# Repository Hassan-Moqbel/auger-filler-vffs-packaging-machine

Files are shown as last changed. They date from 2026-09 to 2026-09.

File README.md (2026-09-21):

# High-Speed Vertical Form Fill Seal (VFFS) Packaging Machine & Precision Auger Dosing System









A fully integrated, publication-grade mechatronic design of an industrial Vertical Form Fill Seal (VFFS) packaging machine with a precision servo-driven auger dosing unit. This capstone engineering project encompasses complete 3D SolidWorks parametric modeling of the entire machine, rigorous ANSYS Workbench finite element structural validation across three progressive load cases, analytical volumetric and torque calculations verified against empirical calibration data, and embedded ESP32 motion control firmware — delivering a production-ready system engineered to package $500\text{ g}$ doses of granular NaCl powder at $15\text{ bags/min}$ with sub-percent gravimetric accuracy through $4.5$ precision servo-metered auger revolutions.

<p align="center">
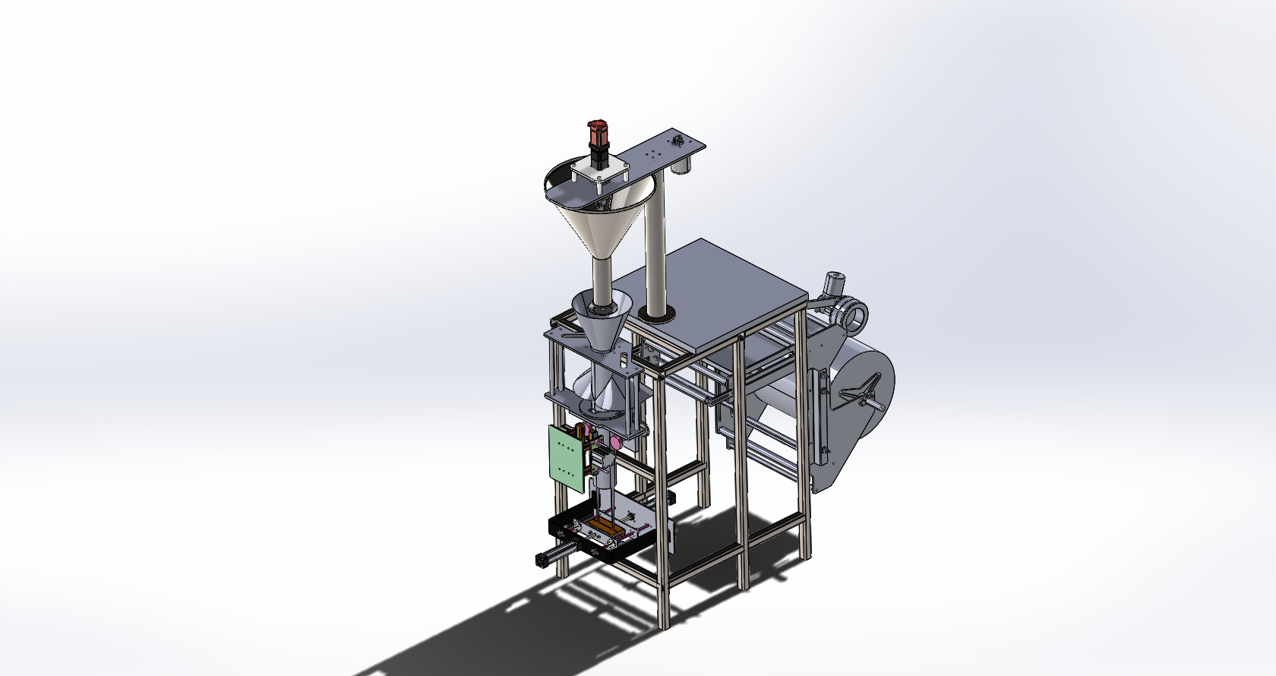
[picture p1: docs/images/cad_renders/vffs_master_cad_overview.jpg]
VFFS Auger Filler CAD Master Assembly Overview
  
  <br/>
  <em>Fig. 1 — Complete VFFS Machine Assembly: Conical Hopper, Servo-Driven Auger Dosing Head, Film Forming Shoulder, and Pneumatic Cross-Seal Jaws.</em>
</p>

---

## Industrial Standards & Hygienic Food-Contact Compliance

This VFFS machine architecture strictly adheres to international food packaging machinery standards:

- **EHEDG & FDA 21 CFR Part 110 (Hygienic Food-Contact Surfaces):** All product-wetted components (auger screw, hopper interior, rotary plate, funnel bore) fabricated from **AISI 316L Stainless Steel** with electropolished surface finish: auger and funnel $R_a \le 1.6\ \mu\text{m}$, hopper interior $R_a \le 0.8\ \mu\text{m}$. All internal fillet radii exceed $6\text{ mm}$ to eliminate dead-zone crevices for complete CIP/COP sanitation cycles without disassembly.
- **ISO 13849-1 / IEC 62061 (Functional Safety):** Dual-channel redundant emergency stop architecture on sealing jaw pneumatic cylinders, film nip rollers, and auger servo drive. System engineered to **Performance Level d (PL d, Category 3)** with fail-safe zero-energy state on safety guard door interruption.
- **DIN EN 415-4 (VFFS Machine Safety):** Vertical form fill seal machine-specific safety directives governing forming shoulder access zones, cross-seal jaw pinch point interlocks, film web tension roller guards, and auger dosing head lockout/tagout procedures.

---

## Executive Engineering KPIs & Physical Parameters

| Parameter | Symbol | Design Value | Verified Benchmark |
| :--- | :--- | :--- | :--- |
| **Packaging Throughput** | — | $\ge 15\text{ bags/min}$ | $15\text{ bags/min (intermittent cycle)}$ |
| **Fill Target Mass** | $m_{\text{target}}$ | $500\text{ g} \pm 0.5\%$ | $500.0\text{ g (4.5 servo revolutions)}$ |
| **Powder Bulk Density** | $\rho_b$ | $1200 - 1300\text{ kg/m}^3$ | $1300\text{ kg/m}^3\text{ (NaCl, fine grade)}$ |
| **Auger Outer Diameter** | $D$ | $60\text{ mm}$ | $60.0 \pm 0.2\text{ mm}$ |
| **Auger Core Shaft Diameter** | $d$ | $16\text{ mm}$ | $16.00^{+0.00}_{-0.02}\text{ mm (h6 fit)}$ |
| **Auger Pitch** | $p$ | $60\text{ mm}$ | $60.0 \pm 0.5\text{ mm/flight}$ |
| **Active Helical Flights** | $N$ | $4$ | $4\text{ full turns}$ |
| **Flighted Conveying Length** | $L_f$ | $228\text{ mm}$ | $228\text{ mm}$ |
| **Total Shaft Length** | $L_t$ | $350\text{ mm}$ | $350\text{ mm (incl. coupling zone)}$ |
| **Volumetric Fill Efficiency** | $\eta_v$ | $0.60$ | $0.60\text{ (empirical NaCl calibration)}$ |
| **Dosing Revolutions per Bag** | $N_{\text{rev}}$ | $4.5$ | $4.5\text{ precision servo revolutions}$ |
| **Servo Motor** | — | $P \ge 400\text{ W}$ | Panasonic MSMF042L1U1 (MINAS A6) |
| **Rated Servo Torque** | $T_{\text{rated}}$ | — | $1.27\text{ Nm at 3000 RPM}$ |
| **Planetary Gearbox** | — | $i = 1{:}20$ | Apex Dynamics AB060A-020, $\eta > 95\%$ |
| **Output Torque at Auger** | $T_{\text{output}}$ | — | $24.13\text{ Nm at 150 RPM}$ |
| **FEA Mesh Element Size** | — | $1.0\text{ mm}$ | Resolution Level 7 (Maximum Fidelity) |
| **FEA Mesh Skewness** | — | $< 0.25$ | $0.12096\text{ (excellent quality)}$ |
| **Structural Safety Factor** | $\text{FoS}$ | $\ge 2.0$ | $\ge 2.5\text{ (all critical load paths)}$ |
| **Surface Finish (Auger)** | $R_a$ | $\le 1.6\ \mu\text{m}$ | Electropolished SS316L |
| **Hopper Capacity** | — | $20\text{ kg}$ | Conical geometry, anti-bridge agitator |

---

## Electromechanical Power Transmission & Dosing Architecture

```mermaid
flowchart TD
    subgraph DriveTrain[Precision Servo Drive Train]
        SERVO[Panasonic MSMF042L1U1 400W AC Servo Motor]
        GEARBOX[Apex AB060A-020 1:20 Planetary Reducer]
        COUPLING[Rigid Flange Coupling with Cross-Pin]
        SERVO -->|3000 RPM / 1.27 Nm Rated| GEARBOX
        GEARBOX -->|150 RPM / 24.13 Nm Output| COUPLING
    end

    subgraph DosingHead[Auger Dosing Head Assembly]
        HOPPER[Conical Hopper 20kg with Anti-Bridge Agitator]
        AUGER[Precision Helical Auger D=60mm p=60mm SS316L]
        PLATE[Counter-Rotating Rotary Metering Plate]
        COUPLING --> AUGER
        HOPPER -->|Gravity and Agitator Feed| AUGER
        AUGER -->|Volumetric Displacement| PLATE
    end

    subgraph FilmForming[Film Forming and Sealing Subsystem]
        UNWIND[Film Reel Unwinder with Dancer Tensioner]
        FORMER[Forming Shoulder Collar and Tube]
        VSEAL[Vertical Longitudinal Back-Seal Bar]
        HSEAL[Horizontal Pneumatic Cross-Seal Jaws]
        UNWIND --> FORMER
        FORMER --> VSEAL
        VSEAL --> HSEAL
    end

    PLATE -->|Metered Powder Dose 500g| FORMER
    HSEAL -->|Hermetically Sealed Bag| DISCHARGE[Discharge Chute]
```

---

## Intermittent VFFS Machine Cycle — State Machine

```mermaid
flowchart TD
    START([System Power-On and Initialization]) --> IDLE([IDLE: Temperature Setpoints Reached])

    IDLE -->|HMI Start Trigger| FILM_ADV[FILM ADVANCE: Pull Web to Target Bag Length]
    FILM_ADV -->|Web Position Sensed| V_SEAL[VERTICAL SEAL: Back-Seal Bar Clamped]

    V_SEAL -->|Tube Formed and Locked| DOSING[AUGER DOSING: 4.5 Servo Revolutions]
    DOSING -->|Servo Position Complete| DWELL[DWELL AND SETTLE: Powder Settles in Bag]

    DWELL -->|Dwell Timer Expired| H_SEAL[HORIZONTAL SEAL: Cross-Seal Pneumatic Clamp]
    H_SEAL -->|Thermal Seal Timer Expired| CUT[CUT AND DISCHARGE: Pneumatic Knife Actuation]

    CUT -->|Bag Discharged to Chute| CYCLE_CHECK{Continuous Automatic Run?}
    CYCLE_CHECK -->|Yes / Automatic Cycle| FILM_ADV
    CYCLE_CHECK -->|No / Stop Command| IDLE

    %% Safety Interlocks
    FILM_ADV -.->|Safety Guard Interruption| ESTOP([E-STOP: Fail-Safe Zero-Energy State])
    DOSING -.->|Servo Torque Overload| ESTOP
    H_SEAL -.->|Jaw Thermal Runaway| ESTOP
    ESTOP ==>|Manual Reset and Acknowledge| IDLE
```

---

## Theoretical & Mathematical Formulations

### 1. Helical Auger Volumetric Pitch Displacement

The theoretical volume displaced per single revolution of the auger screw is governed by the annular cross-sectional area of the helical flight channel:

$$
V_{\text{pitch}} = \frac{\pi}{4} (D^2 - d^2) \cdot p
$$

Substituting the verified design parameters ($D = 60\text{ mm}$, $d = 16\text{ mm}$, $p = 60\text{ mm}$):

$$
V_{\text{pitch}} = \frac{\pi}{4} (0.060^2 - 0.016^2) \times 0.060 = 1.567 \times 10^{-4}\text{ m}^3 = 156.7\text{ cm}^3
$$

### 2. Metered Dosing Revolution Kinematics

The number of servo-metered revolutions required to deliver the target mass $m_{\text{target}}$ through a volumetric displacement system is:

$$
N_{\text{rev}} = \frac{m_{\text{target}}}{\rho_b \cdot V_{\text{pitch}} \cdot \eta_v}
$$

Evaluating with the calibrated bulk density and fill efficiency:

$$
N_{\text{rev}} = \frac{0.500}{1300 \times 1.567 \times 10^{-4} \times 0.60} = \frac{0.500}{0.12222} \approx 4.09
$$

A real-world settling and aeration margin of $+10\%$ is applied, yielding the operational setpoint $N_{\text{rev}} = 4.5\text{ revolutions/dose}$.

### 3. Drive Train Dynamic Sizing & Torque Verification

The total resistive torque at the auger shaft encompasses four distinct loading mechanisms:

$$
T_{\text{total}} = T_{\text{material}} + T_{\text{friction}} + T_{\text{bearing}} + T_{\text{inertia}}
$$

The Panasonic MSMF042L1U1 delivers rated torque $T_{\text{rated}} = 1.27\text{ Nm}$ at $3000\text{ RPM}$. Through the Apex AB060A-020 planetary reducer ($i = 20$, $\eta = 0.95$):

$$
T_{\text{output}} = T_{\text{rated}} \times i \times \eta = 1.27 \times 20 \times 0.95 = 24.13\text{ Nm}
$$

$$
n_{\text{output}} = \frac{3000}{20} = 150\text{ RPM}
$$

This output torque provides substantial reserve above the calculated total demand, ensuring reliable start-up and operation under worst-case powder compaction surge loads.

### 4. Forming Shoulder Web Tension — Euler-Eytelwein Capstan Model

The flat BOPP packaging film wrapping around the forming shoulder collar follows the classical capstan friction model. The tension ratio between the tight side and slack side obeys:

$$
\frac{T_{\text{tight}}}{T_{\text{slack}}} = e^{\mu \theta}
$$

For BOPP film on polished stainless steel ($\mu = 0.25$, wrap angle $\theta = \pi\text{ rad}$):

$$
\frac{T_{\text{tight}}}{T_{\text{slack}}} = e^{0.25 \pi} \approx 2.19
$$

This dictates the minimum pull-belt grip force required to maintain consistent film tracking without slip or wrinkling across the forming shoulder.

### 5. Horizontal Sealing — Pneumatic Clamping & Conductive Heat Transfer

The sealing jaw clamping force from the pneumatic cylinder at system pressure $P_{\text{sys}}$ with bore $D_{\text{cyl}}$:

$$
F_{\text{clamp}} = P_{\text{sys}} \cdot \frac{\pi D_{\text{cyl}}^2}{4}
$$

The thermal energy conducted across the jaw-film interface during the seal dwell period follows Fourier's law:

$$
Q = k_{\text{jaw}} \cdot A_{\text{seal}} \cdot \frac{\Delta T}{L_{\text{jaw}}} \cdot t_{\text{dwell}}
$$

The dwell time $t_{\text{dwell}}$ must exceed the minimum energy threshold to achieve molecular chain entanglement across both BOPP film layers while remaining below the thermal degradation onset temperature of the polymer substrate.

---

## ANSYS FEA Structural Validation & Stress Analysis

Three progressive static structural analysis cases were executed in ANSYS Mechanical to verify component integrity under representative operational loading:

| Case | Analysis Scope | Boundary Conditions | Material | Result |
| :--- | :--- | :--- | :--- | :--- |
| **Case 1** | Auger Screw (Solo) | Fixed support at coupling face; distributed torsional load at flight surfaces | SS316L ($\sigma_y = 205\text{ MPa}$) | $\text{FoS} \ge 2.5$ at flight root fillets |
| **Case 2** | Auger + Shaft Assembly | Fixed at bearing seats; torque at keyway; axial powder backpressure | SS304 ($\sigma_y = 215\text{ MPa}$) | $\text{FoS} \ge 2.5$ at J-Slot stress concentrators |
| **Case 3** | Auger + Shaft + Rotary Plate | Combined torsion, axial, and radial bearing reaction loads | SS316L / SS304 | $\text{FoS} \ge 2.0$ under full compaction loading |

**Mesh Quality Metrics:**

| Setting | Value | Purpose |
| :--- | :--- | :--- |
| Element Size | $1.0\text{ mm}$ | High spatial resolution for stress gradient capture |
| Adaptive Sizing | Enabled | Automatic refinement at geometric features |
| Resolution Level | 7 (Maximum) | Highest fidelity surface representation |
| Smoothing | High | Node repositioning to minimize element distortion |
| Transition | Slow | Gradual element size graduation |
| Span Angle Center | Fine | Dense meshing at curved surfaces |
| Method (Auger) | Tetrahedral, Patch Independent | Robust meshing of helical geometry |
| Skewness (Average) | $0.12096$ | Excellent mesh quality (threshold $< 0.25$) |
| Error Limits | Aggressive Mechanical | Strict quality gates on element shape |

---

## Design Failure Mode & Effects Analysis (DFMEA)

| Failure Mode | Root Cause | Severity | Engineering Mitigation |
| :--- | :--- | :--- | :--- |
| **Powder Bridging / Rat-Holing** | NaCl hygroscopic caking at hopper walls under ambient humidity | High | Counter-rotating agitator blades with variable speed drive; SS316L polished hopper interior ($R_a \le 0.8\ \mu\text{m}$) with $70^\circ$ minimum cone half-angle ensuring mass-flow discharge. |
| **Seal Contamination by Powder Dust** | Fine airborne particles settling on cross-seal jaw contact surfaces | Critical | Positive-pressure air curtain blown laterally across jaw face during dosing phase; vacuum dust extraction hood at forming tube discharge. |
| **Film Tracking Drift & Wrinkling** | Asymmetric web tension from reel eccentricity or thermal film expansion | Medium | Servo-tensioned unwinder with ultrasonic edge-position sensor closed-loop feedback; spring-loaded dancer roller maintaining constant back-tension. |
| **Sealing Jaw Thermal Runaway** | PID heater controller failure or thermocouple mechanical detachment | Critical | Redundant Type-K thermocouple pair with independent hardware over-temperature relay cutoff at $T_{\text{max}} + 15^\circ\text{C}$, wired directly to safety contactor. |
| **Auger Shaft Fatigue at Keyway** | Cyclic torsional stress concentration at J-Slot fillet root during start-stop dosing cycles | High | Generous fillet radii ($r \ge 2\text{ mm}$) at all stress concentrators; FEA-validated $\text{FoS} \ge 2.5$ under worst-case compaction torque. |

---

## System Visual Gallery

<p align="center">
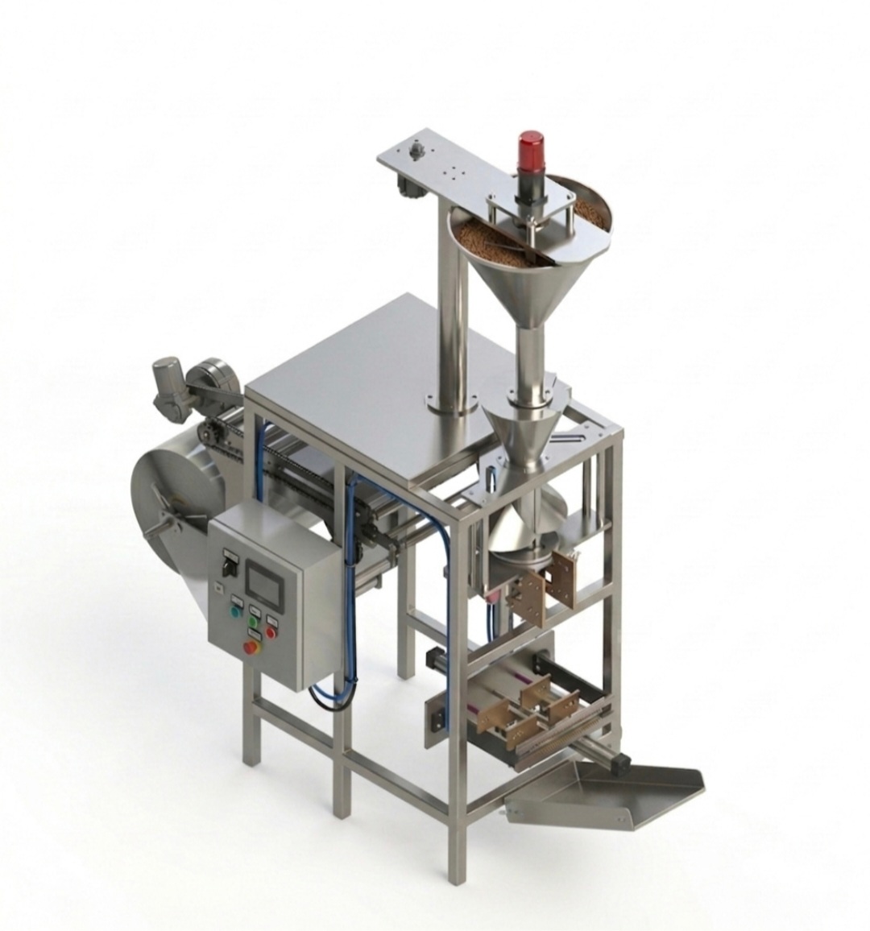
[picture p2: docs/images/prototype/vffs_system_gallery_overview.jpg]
VFFS Machine — Multi-Angle System Gallery
  
  <br/>
  <em>Fig. 2 — VFFS Machine System Gallery: Auger dosing head assembly, forming collar film transition, horizontal sealing jaw mechanism, and complete machine integration views.</em>
</p>

---

## Repository Architecture & Artifact Catalog

| Directory | Contents | Description |
| :--- | :--- | :--- |
| [`cad/assemblies/`](cad/assemblies/) | `.sldasm`, `.sldprt` | Master VFFS assembly and key functional subassemblies |
| [`cad/parts/`](cad/parts/) | `.sldprt`, `.step` | Essential mechanical components (auger, shaft, hopper, jaws, frame) |
| [`cad/drawings/`](cad/drawings/) | `.dxf`, `.slddrw` | 2D fabrication and shop drawings |
| [`simulation/fea/`](simulation/fea/) | ANSYS projects | FEA mesh, boundary conditions, stress contour results |
| [`firmware/src/`](firmware/src/) | `.ino`, `.cpp`, `.h` | Embedded ESP32/Arduino motion control firmware |
| [`calculations/`](calculations/) | `.xlsx` | Parameter-driven volumetric, torque, and sizing spreadsheets |
| [`datasheets/`](datasheets/) | `.mdb`, `.txt` | Panasonic MINAS A6 motor and Apex gearbox configuration files |
| [`docs/reports/`](docs/reports/) | `.docx`, `.pdf` | Graduation thesis chapters and official engineering reports |
| [`docs/images/`](docs/images/) | `.png`, `.jpg`, `.mp4` | Curated CAD renders, FEA contour plots, and prototype photos |

> Standard hardware components (fasteners, bearings, gaskets), raw solver databases, and redundant CAD variants are preserved in the local `_archive/` directory (excluded from Git tracking via `.gitignore`).

---

## License

This Capstone Engineering Project is licensed under the [MIT License](LICENSE).

---

**Hassan Moqbel Morshed Ghaleb**
Mechatronics Engineer | Mechanical Design & CAD (SolidWorks & AutoCAD) | Preventive Maintenance & Electromechanical Systems | Industrial Automation, Control Systems, Robotics & Intelligent Machines | CAD/FEA, Embedded Systems, Python & C++

[GitHub](https://github.com/Hassan-Moqbel) · [LinkedIn](https://www.linkedin.com/in/hassan-moqbel) · [Facebook](https://www.facebook.com/share/1BqxAgVjHi/)

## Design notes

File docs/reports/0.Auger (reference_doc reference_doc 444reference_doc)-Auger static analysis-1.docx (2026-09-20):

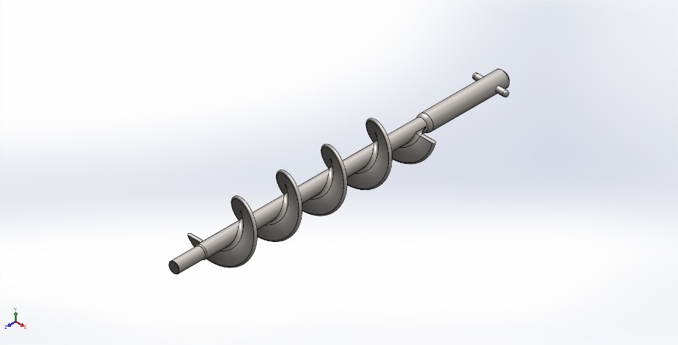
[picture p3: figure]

Simulation of 0.Auger (الطول الكلي 444سم)

Date: Saturday, January 3, 2026
Designer: Solidworks

Study name: Auger static analysis

Analysis type: Static
Description No Data

# Assumptions

# Model Information

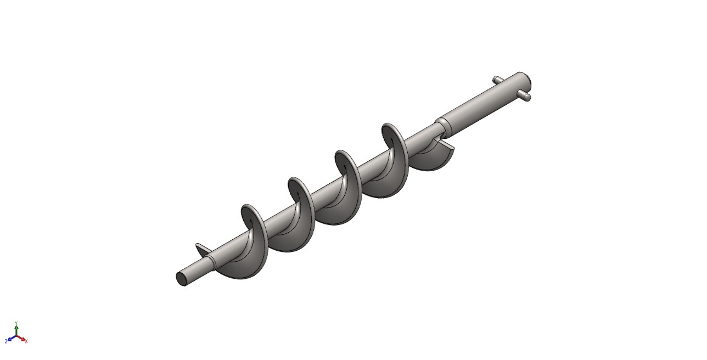
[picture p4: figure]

Model name: 0.Auger (الطول الكلي 444سم)

Current Configuration: Default

Solid Bodies
Document Name and Reference | Treated As | Volumetric Properties | Document Path/Date Modified

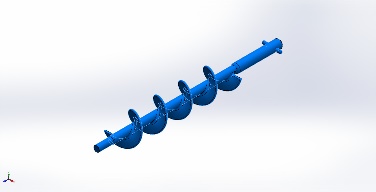
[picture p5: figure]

Fillet16 | Solid Body | Mass:1.17612 kg Volume:0.000147026 m^3 Density:7,999.35 kg/m^3 Weight:11.5259 N | C:\Users\user1\Desktop\0.Auger (الطول الكلي 444سم).SLDPRT

# Study Properties

Study name | Auger static analysis
Analysis type | Static
Mesh type | Solid Mesh
Thermal Effect: | On
Thermal option | Include temperature loads
Zero strain temperature | 298 Kelvin
Include fluid pressure effects from SOLIDWORKS Flow Simulation | Off
Solver type | Automatic
Inplane Effect: | Off
Soft Spring: | Off
Inertial Relief: | Off
Incompatible bonding options | Automatic
Large displacement | Off
Compute free body forces | On
Friction | Off
Use Adaptive Method: | Off
Result folder | SOLIDWORKS document (C:\Users\user1\Desktop)

# Units

Unit system: | SI (MKS)
Length/Displacement | mm
Temperature | Kelvin
Angular velocity | Rad/sec
Pressure/Stress | N/m^2

# Material Properties

Model Reference | Properties | Components

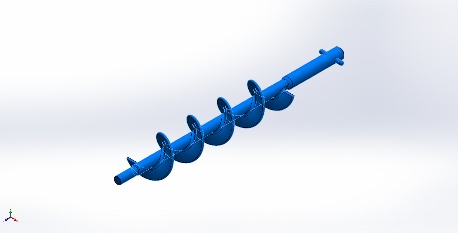
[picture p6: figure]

| Name: AISI 304 Model type: Linear Elastic Isotropic Default failure criterion: Max von Mises Stress Yield strength: 2.06807e+08 N/m^2 Tensile strength: 5.17017e+08 N/m^2 Elastic modulus: 1.9e+11 N/m^2 Poisson's ratio: 0.29 Mass density: 8,000 kg/m^3 Shear modulus: 7.5e+10 N/m^2 Thermal expansion coefficient: 1.8e-05 /Kelvin | SolidBody 1(Fillet16)(0.Auger (الطول الكلي 444سم))

Curve Data:N/A

# Loads and Fixtures

Fixture name | Fixture Image | Fixture Details

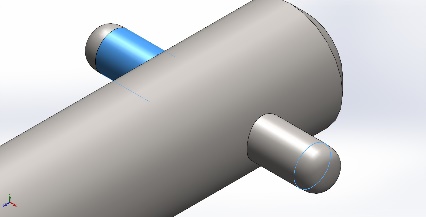
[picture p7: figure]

Fixed-1 | | Entities: 1 edge(s), 1 face(s) Type: Fixed Geometry

Resultant Forces

Components | X | Y | Z | Resultant
Reaction force(N) | -48.1414 | -1.24923 | 0.00227994 | 48.1576
Reaction Moment(N.m) | 0 | 0 | 0 | 0

Load name | Load Image | Load Details

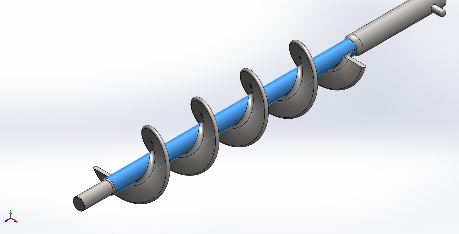
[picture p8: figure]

Torque-1 | | Entities: 1 face(s) Type: Apply torque Value: 20 N.m

# Connector Definitions

No Data

# Interaction Information

No Data

# Mesh information

Mesh type | Solid Mesh
Mesher Used: | Blended curvature-based mesh
Jacobian points for High quality mesh | 16 Points
Maximum element size | 5.27908 mm
Minimum element size | 0.474567 mm
Mesh Quality | High

## Mesh information - Details

Total Nodes | 84219
Total Elements | 50377
Maximum Aspect Ratio | 88.261
% of elements with Aspect Ratio < 3 | 99.6
Percentage of elements with Aspect Ratio > 10 | 0.00993
Percentage of distorted elements | 0
Time to complete mesh(hh;mm;ss): | 00:00:19
Computer name:

# Sensor Details

No Data

# Resultant Forces

## Reaction forces

Selection set | Units | Sum X | Sum Y | Sum Z | Resultant
Entire Model | N | -48.1414 | -1.24923 | 0.00227994 | 48.1576

## Reaction Moments

Selection set | Units | Sum X | Sum Y | Sum Z | Resultant
Entire Model | N.m | 0 | 0 | 0 | 0

## Free body forces

Selection set | Units | Sum X | Sum Y | Sum Z | Resultant
Entire Model | N | 0.364388 | 0.015881 | 0.906562 | 0.977183

## Free body moments

Selection set | Units | Sum X | Sum Y | Sum Z | Resultant
Entire Model | N.m | 0 | 0 | 0 | 1e-33

# Beams

No Data

# Study Results

Name | Type | Min | Max
Stress1 | VON: von Mises Stress | 3.989e+00N/m^2 Node: 25227 | 9.973e+07N/m^2 Node: 81630

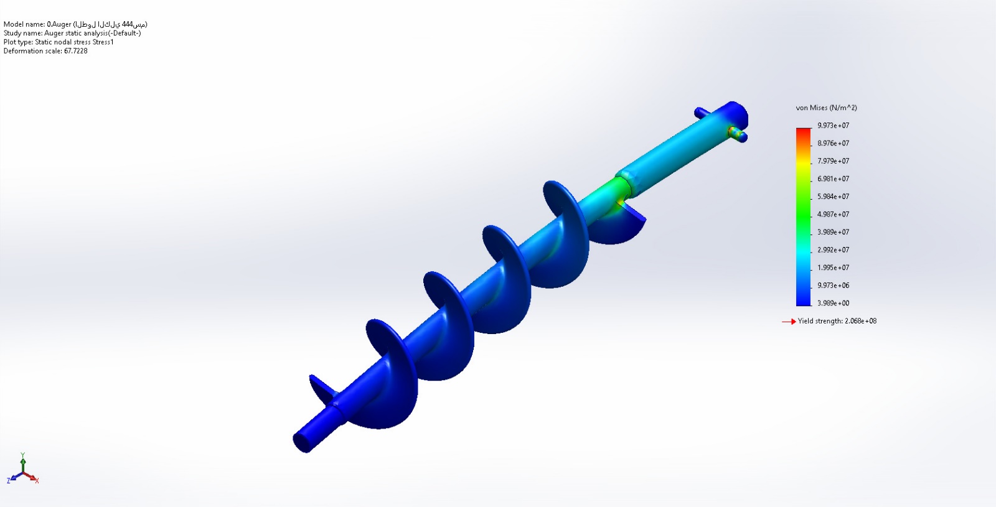
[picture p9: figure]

0.Auger (الطول الكلي 444سم)-Auger static analysis-Stress-Stress1

Name | Type | Min | Max
Displacement1 | URES: Resultant Displacement | 0.000e+00mm Node: 36 | 7.087e-01mm Node: 60633

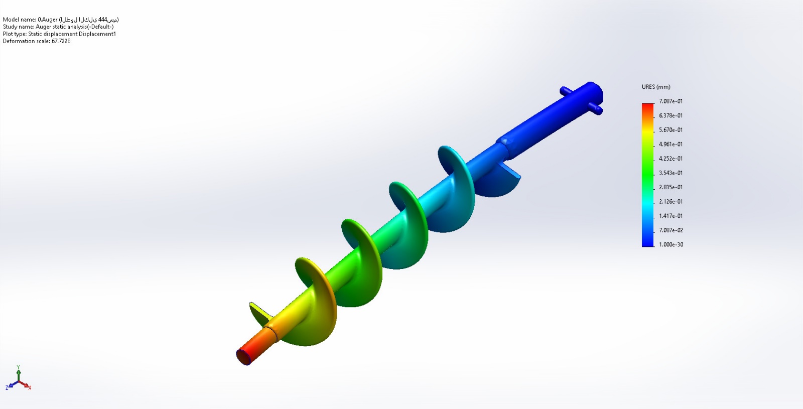
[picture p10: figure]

0.Auger (الطول الكلي 444سم)-Auger static analysis-Displacement-Displacement1

Name | Type | Min | Max
Strain1 | ESTRN: Equivalent Strain | 1.449e-11 Element: 1559 | 3.942e-04 Element: 38209

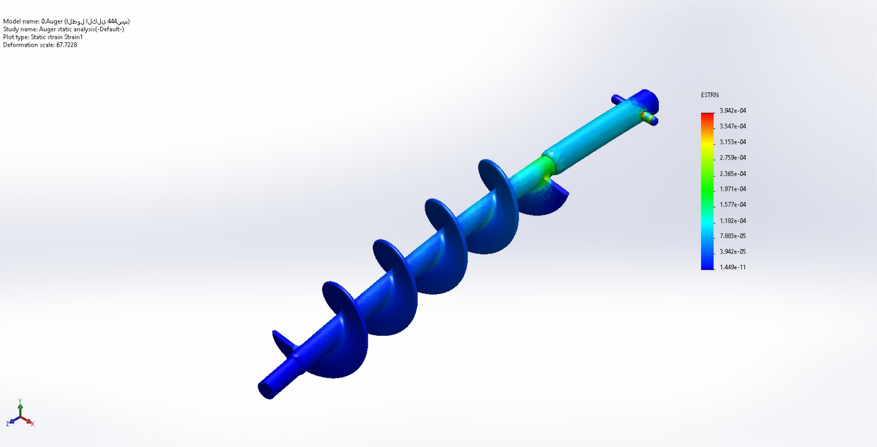
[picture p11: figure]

0.Auger (الطول الكلي 444سم)-Auger static analysis-Strain-Strain1

Name | Type | Min | Max
Factor of Safety1 | Max von Mises Stress | 2.074e+00 Node: 81630 | 5.184e+07 Node: 25227

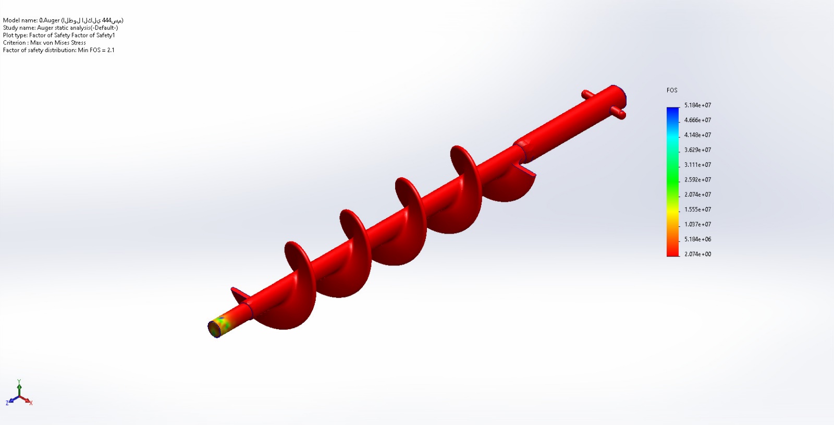
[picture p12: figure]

0.Auger (الطول الكلي 444سم)-Auger static analysis-Factor of Safety-Factor of Safety1

# Conclusion

Analyzed with SOLIDWORKS Simulation Simulation of 0.Auger (الطول الكلي 444سم) 16

Analyzed with SOLIDWORKS Simulation Simulation of 0.Auger (الطول الكلي 444سم) 1

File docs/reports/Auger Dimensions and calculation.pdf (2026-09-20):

Feature | Description | Value | Unit
Overall Length | Total auger length | | 444 mm
Flighted Length | Effective helical section | | 286 mm
Number of Flights | Total helical turns | | 4.5 rev
Pitch | Distance between flights | | 60 mm
Outer Diameter | Maximum auger diameter | | 60 mm
Core Shaft Diameter | Shaft diameter under flight | | 16 mm
Upper Smooth Shaft Length | Non-flighted upper section | | 110 mm
Lower Clearance Length | End clearance before thread | | 16 mm
Threaded Length | Thread for rotary plate | | 35 mm
Thread Diameter | Thread nominal diameter | | 14 mm
Flight Thickness | Helical ribbon thickness | | 4 mm
Radial Flight Height | Flight radial height | | 22 mm
Radial Clearance | Clearance to tube wall | 1.0–1.5 | mm
Fillet | Flight leading edge | 1×45° | -
Fillet Radius | Flight to shaft root | | 4 mm
Fillet Radius | Fillet between Main shaft and smooth shaft | | 9 mm
Fillet Radius | The end of the pin attached to the smooth shaft | R1 = 3.5 | mm
Fillet Radius | The point of contact between the pin and the post | | 0.5 mm
Fillet Radius | The end of the pin attached to the smooth shaft | R2 = 3.49 | mm
Fillet Radius | End of the column connected to the threaded column | | 2 mm
Chamfer | Chamfer end of smooth shaft | 1×45°
Chamfer | Start of the thread column from the bottom | 0.5×45°
Fillet radius | Smoothing the beginning and end of the flight | | 0.5 mm

Notes
Bottom tip to top smooth end Active dosing zone
Single start
Constant pitch
Flight OD
Main core
Connection to auger shaft
Between flight and thread
M14×1.5
Metric fine
Axial thickness
(OD–Core)/2
Avoid rubbing
Smooth flow
Stress relief

On the right side of the smooth column Contact with the smooth column
On the left side of the smooth column

Features | Value | Unit
Out Diameter of spinner plate | | 100 mm
Cut-Extrude diameter in the middle | | 14.5 mm
Diameter of the flat plate before the edge | | 69.55 mm
Thickness of the spinner plate (shell) | | 3 mm
Angle of inclination of the dish's edge | | 55 °
Chamfer in the edge of Cut-Extrude | 0.5×45 | °
Fillet radius | | 3 mm
Cut and extrude inwards by the amount (shell) | | 10 mm
Shell | | 3 mm

Description (English)
Total outer diameter of the spinner plate, defining the maximum extent of the inclined edge.
Central bore diameter, sized to allow passage of the auger shaft or drive spindle.
Diameter of the flat central region before the start of the sloped edge; material rests here before sliding outward. Wall thickness of the spun or formed shell that constitutes the plate.
Conical angle of the outer rim; governs the radial throw and flow pattern of discharged material.
Small 45° chamfer on the bore edge to ease assembly and reduce stress concentration.
Blend radius between adjoining surfaces to minimize stress risers and improve manufacturability. Axial depth of the dished shell, measured from the bottom plane to the top edge of the inclined rim. Indicates the part is a thin-walled shell (constant 3 mm thickness) rather than a solid disc.

Description
القطر الخارجي الكلي للصحن الدوار، وهو القطر األقصى للصحن الذي يحد من حافة اإلمالة الخارجية. قطر الفتحة المركزية المخرمة في منتصف الصحن، تُستخدم لتمرير العمود أو المغزل الذي يُثبت عليه اللولب. قطر المنطقة المستوية من الصحن قبل أن تبدأ الحافة المائلة، وهي المنطقة التي تستقيم عليها المادة قبل أن تنزلق نحو الحافة. سمك الصحن الدوار نفسه، أي سمك الجزء المعدني المكون للصحن. زاوية ميل الحافة الخارجية للصحن، تُستخدم لتوجيه تدفق المادة نحو الخارج أثناء الدوران. شطبة صغيرة عند حافة الفتحة المركزية، تُستخدم لتسهيل التجميع وتقليل التركيز اإلجهادي. نصف قطر التنعيم عند التقاء األسطح، لتقليل التركيز اإلجهادي وتسهيل التصنيع. االرتفاع الرأسي للصحن من السطح السفلي إلى أعلى حافته، أي العمق الداخلي للصحن.
يشير إلى أن الصحن مصمم كـ )" | قشرة | " shell ) أي جسم مجوف ذو سماكة ثابتة من 3 . مم

Feature | Value | Unit
Overall Length | 130 mm
Outer diameter | 30 mm
Length of cut-Extrude on the upper | 30 mm
Diameter of cut-Extrude on the upper | 15 mm
Length of cut-Extrude on the down | 58 mm
Diameter of cut-Extrude on the down | 20 mm
Vertical cut-Extrude length of J-slot | 40 mm
Diameter of the J-slot | | 7 mm
Horizontal cut-Extrude length of J-slot | 13 mm
Vertical Length of the cut on the upper surface | 17 mm
Horizontal Length of the cut on the upper surface | 25 mm
The diameter of the circle allows the cross pin to fit. | 12 mm
Distance of the circle from the top surface of the column | 15 mm
Fillet Radius | 0.5 mm

Description
Total auger shaft length
Maximum auger shaft diameter
Cutting and extruding from the top
The diameter of the cut at the top is intended for the entry of the shaft that connects to the gearbox.
Cutting length - extrusion from the bottom at the point of contact with the smooth shaft of the screw containing two pins The diameter of the cut from below is for the smooth shaft of the screw to enter.
Total length of J-slot cutting and extrusion
The J-slot design allows the insertion of the two pins located in the smooth shaft.
The length of the horizontal cut from the end of the vertical cut of the J-slot
The Vertical length of the cut is on the upper surface of the drill bit on both faces of the bit in order to create a circular opening that allows the insertion of the cross pin.
The Horizontal length of the cut is on the upper surface of the drill bit on both faces of the bit in order to create a circular opening that allows the insertion of the cross pin.
The diameter of the circle at the top, on the cut surface of the shaft, allows for the insertion of a cross-pin to secure the shaft that connects to the shaft connected to the gearbox. The distance of the circle from the top surface of the column, and this circle allows the entry of the contact pin called the Cross-pin
Smoothing of all edges

No. | Force Type | Equation | Symbols Meaning
| 1 Material Weight Force | F_w = m · g | m = mass (kg), g = 9.81 m/s²
| 2 Axial Force (Helix) | F_ax = m · g · sin)α( | α = helix angle
| 3 Normal Force | F_n = m · g · cos)α( | —
| 4 Friction Force | F_f = μ · F_n | μ = friction coefficient
| 5 Axial Friction Force | F_ax,f = μ · m · g · cos)α( | —
| 6 Bulk Pressure Force | F_p = σ · A | σ = bulk stress
| 7 Shear Force | F_s = τ · A | τ = shear stress
| 8 Rotary Plate Load | F_plate = (m_p + m_m) · g | plate + material mass
| 9 Radial Force | F_r = F_n · sin)α( | —
10 Inertial Force | F_i = m · a | a = acceleration
11 Centrifugal Force | F_c = m · ω² · r | ω = angular speed
12 Shaft Tangential Force | F_t = T / r | T = torque
13 Key Shear Force | F_key = T / r_key | r_key = key radius
14 Cross Pin Force | F_pin = T / r_pin | r_pin = pin radius
15 Equivalent Static Force | F_eq = T / r_m | r_m = mean radius

Engineering Use
Gravity load of material
Material conveying force
Used for friction
Material resistance
Affects torque
High fill cases
Cohesion resistance
Load on auger
Bending analysis
Startup condition
Rotating elements
Shaft stress
Key safety
Pin safety
FEA loading

Force Type | Equation | Symbolic Form Input ParametersCalculated Result (Auto) Units
Weight Force | F = m*g | 4.905 m, g | 4.905 N
Axial Friction ForceF = μ*m*g | 1.962 μ, m, g | 1.962 N
Torque from Weight T = F*r | 0.14715 m, g, r | 0.14715 N·m
Centrifugal ForceF = m*r*ω² | 6 m, r, ω | 6 N

Notes | Parameters
Mass (kg) | 0.5
Gravity (m/s^2) | 9.81
Friction Coefficient )μ( | 0.4
Radius (m) | 0.03
Angular Speed (rad/s) | 20
Gravitational force of material Axial resistance
Torque due to mass
Rotational force

Parameter / Equation | Symbol Value Unit | Formula (Excel-driven)
Outer Diameter | D | 0.06 m
Shaft Diameter | Ds | 0.016 m
Pitch | p | 0.06 m
Number of Turns | n | 4.5 -
Fill Efficiency | ηv | 0.6 -
Bulk Density | ρb | 1300 kg/m³
Cross-sectional Area | A | m² | #VALUE!
Volume per Pitch | Vp | m³ | #VALUE!
Effective Volume per Pitch | Veff | m³ | #VALUE!
Total Volume | Vt | m³ | #VALUE!
Mass per Dose | m | kg | #VALUE!

Description
Auger outer diameter
Auger shaft diameter
Auger pitch
Effective auger turns
Volumetric fill efficiency Bulk density of salt
Annular cross-sectional area
Volume conveyed per pitch
Effective volume considering fill efficiency Total conveyed volume
Mass delivered per dose

No. Calculation Item | Equation | Description (Arabic / English)
1 Annular Area | A = π/4 )D² − Ds²( | Effective annular area / | الحلقي | المقطع | مساحة
2 Volume per Revolution | V_rev = A · p | Volume per revolution / لفة | لكل | الحجم
3 Effective Volume | V_eff = η_v · V_rev | Effective volume | الفعلي | الحجم /
4 Total Auger Volume | V_total = V_eff · n | Total volume | الكلي | الحجم /
5 Volumetric Flow Rate | Q_v = V_eff · N | Flow rate / | الحجمي | التدفق | معدل
6 Mass per Revolution | m_rev = ρ_b · V_eff | Mass per rev | لفة | لكل | كتلة /
7 Mass Flow Rate | ṁ = ρ_b · Q_v | Mass flow / | الكتلي | التدفق | معدل
8 Fill Time | t = m_dose / ṁ | Fill time | التعبئة | زمن /
9 Revolutions per Dose | N_dose = m_dose / m_rev | Required turns | اللفات | عدد /
10 Rotation Angle | θ = 360 · N_dose | Rotation angle / | الدوران | زاوية
11 Held Volume | V_hold = A · L_f · η_v | Held volume / | اللولب | داخل | المادة | حجم
12 Held Mass | m_hold = ρ_b · V_hold | Held mass / | اللولب | داخل | كتلة
13 Disc Volume | V_disc = A_disc · h | Disc volume / | الصحن | فوق | المادة | حجم
14 Disc Mass | m_disc = ρ_b · V_disc | Disc mass / | الصحن | فوق | المادة | كتلة
15 Weight Force | F = m · g | Weight force | الوزن | قوة /

Symbols | Engineering Notes
D: Outer diameter | D_s: Shaft diameter | Base volumetric area | | الحجمية | الحسابات | كل | أساس
A: Annular area | p: Pitch | Ideal filling | | كامال ً | امتالء | يفترض ً
η_v: Volumetric efficiency | Includes voids | | االعتبار | بعين | الفراغات | يأخذ
n: Number of turns | Dose basis | | الجرعة | حساب | في | يستخدم
N: rev/s | Speed dependent | | الدوران | بسرعة | مرتبط
ρ_b: Bulk density | Torque input | | الوزنية | للتعبئة | مهم
يستخدم لضبط زمن التعبئة | time Fill b_ρ
m_dose: Target mass | Control timing | | السيرفو | في | التحكم | أساس
يستخدم في التحكم الموضعي | control Position -
θ | Servo command | في | مهمة | Position Control
L_f: Flighted length | Axial load | | االنقطاع | عدم | من | للتأكد
تدخل في حساب العزم | force Axial b_ρ
A_disc: Disc area | Disc load | | األحمال | لتحليل
تؤثر على العزم المحوري | load Axial b_ρ
g: 9.81 m/s² | Static load | | اإلنشائي | التحليل | في | تستخدم

Explanation of the equation and its use تشغلها المادة بين الريشة والعمود
حساب المساحة الفعالة الت ي لفة واحدة
ي

ن
حجم المادة النظرية المنقولة ف تعديل الحجم النظري حسب كفاءة التعبئة
ر | الحجم الذي يحتويه اللولب عب جميع اللفات
وحدة الزمن
ي

ن
حجم المادة المنقولة ف
تحويل الحجم إىل كتلة باستخدام الكثافة الظاهرية الزمن
ي

ن
معدل الكتلة المعبأة ف
الزمن الالزم لتعبئة كتلة محددة عدد لفات اللولب لتعبئة الجرعة زاوية الدوران المطلوبة لكل تعبئة ي

حجم المادة داخل الجزء الحلزون ن كتلة المادة الموجودة داخل اللولب حجم المادة المحمولة عىل الصحن وزن المادة المؤثرة عىل الصحن القوة العمودية الناتجة عن المادة

البند
Part Number
Product
Product Name
Series
Type
Protection Class
Enclosure
Flange Square Dimension
Motor Lead-out Configuration Motor Encoder Connector
Power Supply Capacity
Voltage Specifications
Rated Output
Rated Current (rms)
Holding Brake
Mass
Oil Seal
Shaft Type
Rated Torque
Continuous Stall Torque
Momentary Max. Peak Torque Max. Current (o-p)
Regenerative Brake Frequency Rated Rotational Speed
Max. Rotational Speed
Moment of Inertia of Rotor
Recommended Load-to-Rotor Inertia Ratio Rotary Encoder
Encoder Resolution
Radial Load (Assembly)
Thrust Load A-direction (Assembly) Thrust Load B-direction (Assembly) Radial Load (Operation)
Thrust Load A,B-direction (Operation) Ambient Temperature
Applicable Drivers
Driver Supply Voltage
Driver Interface
Frame Size
Dimensions
Key-way Dimensions
Mounting Screw
Warranty Period
Export Control
Intended Use

Safety Notes

المواصفة
MSMF042L1U1
Servo Motor
MINAS A6 Family Servo Motor MSMF Series
Low Inertia
IP67
محم باستثناء جزء الدوران من عمود اإلخراج وموصالت الموتور واإلنكودر ي
60 mm
Connector
Connector
0.9 kVA
200V
400W
2.4 A
Without
1.2 kg
With
Key-way, center tap
1.27 N·m
1.27 N·m
3.82 N·m
10.2 A
Without option: No limitWith option: No limitExternal Regenerative Resistor Part No.: DVoP4283 3000 r/min
6000 r/min
0.27 × 10⁻⁴ kg·m²
30 times or less
23-bit Absolute/Incremental system 8,388,608
392 N
147 N
196 N
245 N
98.0 N
Derating curve available (see page 4 of datasheet)
MBDLN25NE, MBDLN25SE, MBDLN25SG, MBDLT25NF, MBDLT25SF Single/3-phase 200V
RTEX, Pulse, Modbus (RS485/RS232), Analog
B-Frame
60 mm flange, 129 mm length (installation), 76 mm height, 30 mm shaft length 5h9 width, M5 depth 10
M5, torque: 2.7–3.3 N·m
1 year from purchase or 18 months from manufacture
May require license if used in military applications General-purpose industrial equipment only

Must be installed by qualified personnel; fail-safe design recommended

البند
Part Number
Product
Series
Type
Control Method
System Support
Safety Function
Frame Size
Frequency Response
Supply Voltage
Input Power - Main Circuit Input Power - Control Circuit Encoder Feedback
Absolute System Support
Pulse Input
Pulse Output
Control Signal Input
Control Signal Output
Analog Output
Communication
Regenerative Resistor
Control Modes
Dimensions (W×H×D)
Mass
Mounting Type
Mounting Screw
Connector Types
Warranty Period
Export Control
Intended Use
Safety Notes
Environmental Conditions
Torque Screw Recommendation Smoke Warning
Sulfur Warning
Overvoltage Warning
User Responsibility
Warranty Exclusions

المواصفة
MBDLN25SE
Servo Driver
A6SE Series
Position Control Type
Position Control Only
(ال يدعم النظام المطلق) Only System Incremental Without Safety Function
B-Frame
3.2 kHz
Single/3-phase 200V
Single/3-phase 200 to 240V +10% -15% 50/60 Hz Single-phase 200 to 240V +10% -15% 50/60 Hz 23-bit Absolute/Incremental (8388608 resolution)
(1 = .0.15Pr يجب ضبط) ال يدعم النظام المطلق❌
2 inputs (Photo-coupler input, Line receiver input)
4 outputs (Line driver: 3 outputs, Open collector: 1 output)
( ر | قابلة للبمجة) inputs purpose-general 10
( ر | قابلة للبمجة) outputs purpose-general 6
2 outputs (Analog monitor)
(لإلعداد والمراقبة فقط) USB
ال يحتوي عىل مقاومة تجديدية داخلية (خارجية فقط) 3 modes:1. Position control2. Internal velocity command3. Position + Internal velocity 55 × 150 × 130 mm
1.0 kg
Base mount / Rack mount (optional brackets)
2-M4 × 6 flat head screw
XA: Main & control power inputXB: Motor & regenerative resistorX1: USBX2: RS232/485X3: Safety function ( 1 year from purchase or 18 months from manufacture
تطبيقات عسكرية
ي

ن
قد يتطلب ترصيحً ا إذا استخدم ف

General-purpose industrial equipment only تطبيقات حساسة
ي

ن
مختص، تصميم آمن ضد األعطال، ال يستخدم ف
ن | كيب من قبل فت ي
يجب الب ( ، طبان
ر | إال بعد استشارة الش | ...) كة | ر | نووي، طت ي
ُ راجع الدليل للتفاصيل
ي
2.7–3.3 N·m | لمسامب | M5
حالة العطل
ي

ن
قد ينبعث دخان ف (ما يعادل سيجارة واحدة)
ر | بيئات تحتوي عىل كبيت أو غازات حامضية
ي

ن
ال يستخدم ف
ن حت ال يؤدي إىل حريق أو تلف

ال يتجاوز الجهد المقي ن

ي

والقانون ن
ي

المستخدم مسؤول عن التوافق الميكانيك والكهربان ي
ن | ال يشمل.1: االس تخدام الخاط أو التعديل.2 التلف أثناء النقل أو السقوط.3 ام بالمواصفات
عدم االلب .4 الكوارث الطبيعية.5 دخول مواد غريبة (ماء، زيت، معدن...)

RS232/485X3: Safety function ( | مستخدم | غب( X4: InterfaceX5: External scale ( | مستخدم | غب( X6: Encoder

المواصفة البند
Part Number | AB060A-020-S2-P1
Series | AB Series (High Precision Planetary Gearbox)
Frame Size | AB060A
Stage | 2 Stage
Ratio | 20
Shaft Option | S2: Output Shaft with Key
Backlash Class | P1: Reduced Backlash (≤5 arcmin)
Nominal Output Torque (T2N) | 60 Nm
Emergency Stop Torque (T2NOT) | 180 Nm (3 × T2N)
Max. Input Speed (n1B) | 10,000 rpm
Nominal Input Speed (n1N) | 5,000 rpm
Efficiency | ≥94% (2-stage)
Backlash (P1) | ≤5 arcmin
Torsional Rigidity | 7 Nm/arcmin
Max. Radial Load (F2rB) | 3,250 N
Max. Axial Load (F2aB) | 765 N
Service Life | 10,000 hrs (continuous operation)
Operating Temperature | -10°C to +90°C
Lubrication | Synthetic oil ( | الحياة | مدى(
Protection Class | IP65
Mounting Position | All directions
Noise Level (at 3000 rpm, no load) | ≤58 dB(A)
Mass | 1.9 kg
Inertia (J1) | 0.47 kg·cm²
Motor Shaft Diameter (C3) | 14 mm (inferred from image and bushing note)

القيمة (mm (البند
D1 | 70
D2 | 5.5
D3 | 16
D4 | 50
D5 | 45
D6 | M5 x 0.8P
D7 | 80
L1 | 60
L2 | 37
L3 | 7
L4 | 1.5
L5 | 25
L6 | 2
L7 | 6
L8 | 98
L9 | 4.8
L10 | 12.5
C1 | 70
C2 | M5 x 0.8P
C4 | 34
C5 | 50
C6 | 8
C7 | 60
C8 | 19
C9 | 154
C10 | 13.5
B1 | 5
H1 | 18

Item | Symbol / Equation Numerical Substitution
Filled Mass | m | 0.5
Gravity Acceleration | g | -
Material Weight | W = m·g | 0.5×9.81
Outer Radius | r_o | 60/2
Inner Radius | r_i | 16/2
Mean Radius | r_m=(r_o+r_i)/2 | (0.03+0.008)/2
Torque due to Weight | T_weight=W·r_m | 4.905×0.019
Friction Coefficient | μ | -
Axial Friction Force | F_f=μ·W | 0.3×4.905
Friction Torque | T_f=F_f·r_m | 1.47×0.019
Wall Friction Torque | T_wall | Conservative
Bearing Friction Torque | T_bearing | Estimate
Inertia Torque | T_inertia | Startup estimate
Total Raw Torque | ΣT | Sum)7→13(
Safety Factor | SF | -
Design Torque | T_design=SF·ΣT | 2.5×0.151
Gear Ratio | i | -
Gearbox Efficiency | η | -
Required Servo Torque | T_s=T_d/)i·η( | 0.378/(20×0.95)
Servo Rated Torque | Datasheet | MSMF042L1U
Servo Peak Torque | Datasheet | -
Gearbox Output Torque T_out=T_s·i·η | 0.16×20×0.95
Effective Safety Factor | T_out/T_design | 3.04/0.378
Design Status | - | -

Result | Unit | Engineering Note
0.5 | kg | Target fill weight
9.81 | m/s² | Physical constant
4.905 | N | Weight force
0.030 | m | Auger outer radius
0.008 | m | Shaft radius
0.019 | m | Force application radius
0.093 | N·m | Basic conveying torque
0.30

### - Fine salt

1.47 | N | Material resistance
0.028 | N·m | Internal friction torque
0.010 | N·m | Flight-wall contact
0.0002 | N·m | Bearing losses
0.020 | N·m | During acceleration
0.151 | N·m | Without safety factor
2.5

### - Industrial practice

0.378 | N·m | Required on auger
20

### - Planetary gearbox

0.95

### - High precision gearbox

0.020 | N·m | Actual servo load
0.16 | N·m | Continuous operation
0.48 | N·m | Acceleration peak
3.04 | N·m | Available torque
≈8

### - Very safe SAFE

### - No resizing required

No. Torque Name | Equation
1 Material Weight Torque | T_m = m·g·r_m
2 Axial Friction Torque | T_a = μ·m·g·r_m
3 Shear Torque | T_s = τ·A·r_m
4 Wall Friction Torque | T_w = μ_w·N·r_o
5 Bearing Friction Torque | T_b = f_b·F_r·r_b
6 Coupling/Key Loss Torque | T_k ≈ μ·F·r
7 Screw Inertia Torque | T_J = J·α
8 Material Inertia Torque | T_Jm = J_m·α
9 Total Raw Torque | T_raw = ΣT
10 Design Torque | T_design = SF·T_raw
11 Required Servo Torque | T_servo = T_design /)G·η(
12 Gearbox Output Torque | T_out = T_servo·G·η
13 Actual Safety Factor | SF_actual = T_out / T_design

Symbols Description | Engineering Purpose
m: mass, g: gravity, r_m: mean radius | Torque due to material weight
μ: friction coefficient | Axial resistance of material
τ: shear stress, A: shear area | Material internal shear
μ_w: wall friction, N: normal force | Flight-wall friction
f_b: bearing factor | Bearing resistance
- Losses in coupling/key
J: inertia, α: angular accel. | Startup torque
J_m: material inertia | Material dynamic torque
- Sum of all torques
SF: safety factor | Design condition
G: gear ratio, η: efficiency | Motor sizing
- Available torque
- Safety check

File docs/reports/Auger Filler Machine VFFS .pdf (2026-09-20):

## SANA'A UNIVERSITY FACULTY OF ENGINEERING MECHATRONICS ENGINEERING DEPARTMENT

## Design, Analytical Modeling, and Multiphysics Simulation-Based Validation of an Industrial Auger Filler Machine for VFFS Powder Packaging Systems

## Prepared by:

## Hassan Moqbel Morshed Ghaleb - 202274198 Musa Ali Hassan Al-salmani - 202174202 Abdulrahim Yasser Abdulrahim Ghanem - 202173006 Suhaib Abduallah Al-Malhani - 202174006 Hamzah Abdulqawi Al-khalaf - 202274127 Ehab Abdulkarim Ai-Qubati - 202174125

## Supervised by:

## Dr. Abdullah Dhaiban

A final year project Submitted in partial fulfillment of the requirements for the award of the degree of Bachelor of Engineering in Mechatronics Engineering

## April, 2026

i

## DECLARATION

We hereby declare that this thesis is our original work and has been written by us in its entirety. We certify that we have duly acknowledged all the sources of information which have been used in the thesis. This work is being submitted in partial fulfillment of the requirements for the award of the degree of Bachelor of Engineering and submitted in Sana’a University, faculty of Engineering, Department of Mechatronics Engineering.
We would like to express our gratitude to:
Dr. Abdullah Dhaiban.

for their guidance and support throughout the research process. Additionally, we would like to dedicate this work to our families, who have supported us throughout the entire project.

Hassan Moqbel Morshed Ghaleb - 202274198
Musa Ali Hassan Al-salmani - 202174202 Abdulrahim Yasser Abdulrahim Ghanem - 202173006 Suhaib Abduallah Al-Malhani - 202174006
Hamzah Abdulqawi Al-khalaf - 202274127
Ehab Abdulkarim Ai-Qubati - 202174125

April, 2026

ii

## ACKNOWLEDGEMENTS

First and foremost, we express our thanks and praise to Allah Almighty for His guidance and success granted to us throughout our research period, which enabled us to complete this research successfully. We also extend our deepest thanks and gratitude to our esteemed supervisor, Dr. Abdullah Dhaiban, for his continuous guidance, insightful technical vision, and for sharing a wealth of new information with us. We are immensely grateful for everything he has provided. We also thank him for his friendship, support, and constructive feedback throughout the
development of this project. Furthermore, we must not forget to extend our sincere thanks to the faculty members of the Mechatronics Engineering Department, especially the Head of Department, Prof Dr Abdulmalik Momin and to the Al-Ansar Foundation for providing the academic environment and necessary resources to accomplish this work.

Secondly, we would like to express our profound thanks to our parents for their backing and support in completing this project. We are deeply grateful for their love, prayers, patience, and belief in us. The authors also express their gratitude to all members of the project team for their cooperation, shared responsibilities, and technical contributions that led to the successful completion of the integrated powder filling machine system.

Finally, we extend our thanks and appreciation to our families and friends for their continuous support, understanding, and encouragement throughout the duration of this project. Their belief in our abilities and their constant motivation were crucial factors in overcoming obstacles and keeping us focused on our goals. Although we cannot mention everyone by name, we sincerely appreciate the contributions of all those who helped us, directly or indirectly.

Thank you all for your support and contributions.

iii

## ABSTRACT

This project is about designing a mechatronic system for a vertical form fill seal machine that uses ESP32, specifically for packaging powder stuff. It pulls together the forming, filling, and sealing parts, and adds in some IoT features to fit with Industry 4.0 ideas. Kind of makes the whole process smarter, I guess.

We worked on analytical models for how the powder flows, how the film moves along, the heat sealing process, and the overall dynamics of the system. Then there were these Multiphysics simulations to check everything, like finite element analysis, discrete element method for the powder, thermal stuff, and even validating the firmware on the ESP32. It helped confirm that the design choices made sense, at least from what I could tell.

The system gets the auger filling, film forming, and thermal sealing to sync up properly, all while monitoring things in real time through a dashboard connected to the cloud. When we validated it, it met the industrial standards for accuracy and how much it can produce, plus reliability. That part stood out, because not every setup nails all that.

Using ESP32 instead of traditional PLC systems cuts costs down by about 60 percent, which is a big deal. It also allows for over the air updates and predictive maintenance, so it feels more future proof. Overall, this gives a framework that others could replicate for designing smart packaging machines, though I might be oversimplifying how easy that would be.

The integration with IoT seems key here, tying back to the Industry 4.0 applications.

iv

## Contents

v

2.1.1 Operating Principles of Vertical Form Fill Seal Machines | 15
2.1.2 Volumetric vs. Gravimetric Dosing: A Comparative Analysis | 17
2.2 Powder Rheology and Handling | 21
2.2.1 Material Characteristics: Bulk Density, Flowability, and Cohesiveness | 21
2.2.2 Dynamics of Screw-Driven Material Transport | 24
2.3 Auger Filler Engineering State-of-the-Art | 26
2.3.1 Geometry Optimization: Pitch, Flight Depth, and Taper | 26
2.3.2 Material Science for Food-Grade Industrial Systems | 29
2.4 Multiphysics in Mechatronic Systems | 31
2.4.1 Review of FEA, Thermal, and Modal Analysis in Rotating Machinery | 31
2.4.2 Integration of Analytical Models with Numerical Simulations | 34
2.5 Research Gap and Summary | 36
2.5.1 Summary of Literature Findings | 36
2.5.2 Identification of Research Gaps | 37
2.5.3 Proposed Contribution of This Study | 38
2.5.4 Comparative Positioning | 40
2.5.5 Rationale for Upcoming Chapters | 41
2.5.6 Concluding Remarks | 41
SYSTEM DESIGN AND SPECIFICATIONS | 43
3.1 Research Design Framework | 43
3.2 Design Requirements and Constraints | 44
3.2.1 Target Output (PPM: Packs Per Minute) and Accuracy (±σ) | 44
3.2.2 Sanitary and Material Standards (e.g., AISI 304 Stainless Steel) | 45
3.3 Conceptual Development | 46
3.3.1 Functional Decomposition (Dosing System, Packaging & Sealing System.) | 46
3.3.2 Selection of Actuation (Servo-driven vs. Induction) | 50
3.4 Final Mechanical Architecture (CAD) | 52
3.4.1 Dosing System CAD: | 52
3.4.2 Packaging and Sealing System CAD: | 54
3.4.2 Drive Train and Power Transmission | 55
3.5 Mechatronic System Architecture | 56
3.5.1 Distributed Processing Strategy (Master-Slave Topology) | 56
3.5.2 Operating System and Task Allocation (FreeRTOS & Dual-Core Strategy) | 57
3.5.3 Mathematical Modeling and Thermal PID Controller | 58
3.5.3 Hybrid Motion Control Logic | 59
3.5.4 Software Architecture of the Finite State Machine (FSM) | 59

vi

3.5.5 Industrial Isolation and Signal Integrity | 60
3.5.6 Industrial Reliability and Protection Protocols (Fail-Safe Logic) | 60
3.7 Summary of Design Specifications | 60
3.6 Electronic Control System Design | 61
3.6.1 System Architecture Overview | 61
3.6.2 Signal Isolation and Conditioning | 62
3.6.3 Temperature Measurement System | 63
3.6.4 Power Actuator Drivers | 64
3.6.5 Solid State Relay Interface | 67
3.6.6 PCB Design and Layout Considerations | 67
3.6.7 Power Budget and Distribution | 69
3.6.8 Pneumatic System Design | 70
3.6.9 Safety and Protection Systems | 70
CHAPTER 4: | Error! Bookmark not defined.
ANALYTICAL MODELING AND ENGINEERING CALCULATIONS | 73
4.1 Mathematical Foundations and Assumptions | 73
4.1.1 Fundamental Assumptions | 73
4.1.2 Material Properties | 74
4.2 Mechanical Modeling of the Dosing System | 74
4.2.1 Hopper Flow Modeling and Geometry Design | 74
4.2.2 Hopper-Agitator Synchronization with the VFFS Cycle | 77
4.2.3 Auger Volumetric and Kinematic Dosing | 77
4.2.4 Dynamic Torque Estimation | 79
4.2.5 Structural Analysis of the Auger Shaft | 81
4.3 Kinematics and Dynamics of Packaging Mechanisms | 82
4.3.1 Film Unwinding and Pulling System | 83
4.3.2 Sealing Jaws Mechanism | 84
4.4 Thermodynamic Modeling of the Sealing System | 84
4.4.1 Heat Transfer in Sealing Jaws | 84
4.4.2 Heater Power Sizing | 85
4.5 Electrical Calculations and Actuator Sizing | 85
4.5.1 Total Power Budget Calculation | 85
4.5.2 Current Calculation and Protection Coordination | 86
4.5.3Auger Mechanism and Load Characterization | 87
4.5.4 Torque Requirement Calculation | 87
4.5.5 Servo Motor and Drive Selection | 88

vii

4.5.6 Servo Drive Specifications | 89
4.5.7 Control Interface Design | 89
4.5.8 Dosing Accuracy Analysis | 90
4.5.9 Power and Thermal Verification | 90
4.5.10 Heating Element Power Requirements | 91
4.5.11 SSR Thermal Analysis | 91
4.5.12 Complete Load Inventory | 92
4.5.12 Protection Coordination Study | 93
4.5.13 Time-Current Coordination | 93
4.5.14 Summary of Analytical Results | 94
4.6 Control System Architecture and Signal Processing | 94
4.6.1 Kinematics of Precision Actuation Systems | 94
4.6.2 PID Temperature Control Modeling | 95
4.6.3 Discrete PID Control and Digital Stability | 96
4.6.3 Microcontroller Processing Requirements | 97
4.7 Overall VFFS System Synchronization | 97
4.7.1 Cycle Timing and In-Flight Material Compensation | 97
4. 8 Summary of Analytical Results | 98
5.1 Computational Setup | 102
5.1.1 Pre-processing: Meshing Strategy and Convergence Study | 102
5.1.2 Material Properties and Boundary Conditions | 104
5.2 Static Structural Analysis | 105
5.2.1 Stress Distribution and Factor of Safety (FOS) | 105
5.2.2 Displacement and Deformation Profiles | 111
5.3 Discrete Element Method (DEM) Simulation and Flow Validation | 117
5.3.1 EDEM Simulation Setup and Parameters | 117
5.3.2 EDEM Simulation Results and Analysis | 118
5.3.2.2 Auger Screw Torque Analysis | 119
5.3.3 EDEM Validation Summary | 120
5.4 Motion Simulation | 120
5.4.1 Motion Simulation Parameters | 120
5.4.2 Dynamic Analysis Results | 121
5.5 Indistrial Validation | 121
5.5.1 Auger and Tooling Validation | 121
5.6 Academic and Research Validation | 122
5.6.1 Material Build-up Prevention | 122

viii

5.6.2 Flow Dynamics Validation | 122
5.7 Thermal PID Controller Simulation and Validation | 122
5.7.1 Model-Based Design Validation | 122
5.7.2 Firmware Validation via Software-in-the-Loop (SIL) | 123
5.8 Comparative Timing Validation: Industrial Standards vs. Simulation Results | 124
5.8.1 Timing Analysis and Validation Results | 125
5.9 Control System Failure Mode and Effects Analysis (FMEA) | 125
5.10 Validation Summary and Correlation Analysis | 126
6.1 Evaluation of Machine Performance | 130
6.1.1 Precision under Variable Operating Speeds | 130
6.1.2 Structural Reliability under Peak Loads | 131
6.2 Suitability for VFFS Industrial Integration | 132
6.2.1 Mechanical Integration | 132
6.2.2 Control System Integration | 132
6.2.3 Operational Workflow | 133
6.3 Discussion of Mechatronic Synergy (How Control Impacts Mechanical Life) | 134
6.3.1 Motion Profile Optimization | 134
6.3.2 Closed-Loop Position Control | 135
6.3.3 Condition Monitoring and Predictive Maintenance | 135
6.4 Contribution to Engineering Knowledge | 136
6.4.1 Integrated Design Methodology | 136
6.4.2 Auger Geometry Optimization for Salt Packaging | 137
6.4.3 Thermal-Structural Coupling Analysis | 138
6.4.4 Servo Control Implementation for Powder Dosing | 138
6.5 Chapter Summary | 139
CONCLUSION AND FUTURE WORK | 142
7.1 INTRODUCTION TO THE CHAPTER | 142
7.2 SUMMARY OF FINDINGS | 142
7.2.1 Mechanical Design Achievements | 142
7.2.2 Analytical Modeling Results | 143
7.2.3 Multiphysics Simulation Validation | 143
7.2.4 Mechatronic Control System Achievements | 144
7.3 RESOLUTION OF RESEARCH QUESTIONS | 145
7.4 FULFILLMENT OF PROJECT OBJECTIVES | 147
7.5 COMPREHENSIVE ANALYTICAL–NUMERICAL CORRELATION | 149
7.6 ADDRESSING THE IDENTIFIED RESEARCH GAPS | 150

ix

7.7 LIMITATIONS OF THE STUDY | 150
7.7.1 Scope Limitations | 151
7.7.2 Modeling Limitations | 151
7.7.3 Material and Component Limitations | 151
7.7.4 Numerical Limitations | 151
7.8 RECOMMENDATIONS FOR PROTOTYPE FABRICATION | 152
7.8.1 Mechanical Fabrication | 152
7.8.2 Electrical and Control Integration | 152
7.8.3 Industrial Safety and Compliance | 153
7.9 DIRECTIONS FOR FUTURE RESEARCH | 153
7.9.1 Near-Term Enhancements (0–12 months) | 153
7.9.2 Medium-Term Development (1–3 years) | 153
7.9.3 Long-Term Research Horizons (3–5 years) | 154
7.10 CONCLUDING REMARKS | 154
References: | 155

## List Of Figure:

FIGURE 1- 1 SCHEMATIC ILLUSTRATION OF VFFS MACHINE WITH INTEGRATED AUGER FILLING SYSTEM
| 5
FIGURE 1- 2 PROJECT METHODOLOGY FLOWCHART SHOWING THE SEQUENTIAL PHASES | 12

FIGURE 2- 1 SCHEMATIC REPRESENTATION OF THE VERTICAL FORM-FILL-SEAL (VFFS) OPERATIONAL
CYCLE | 16
FIGURE 2- 2 STRESS DISTRIBUTION AND CHARACTERISTIC FLOW BEHAVIOR OF BULK COHESIVE SOLIDS
WITHIN A STANDARD HOPPER | 24
FIGURE 2- 3 GEOMETRIC PARAMETERS OF A STANDARD VOLUMETRIC AUGER SCREW | 28
FIGURE 2- 4 TYPICAL FINITE ELEMENT ANALYSIS (FEA) | 32

FIGURE 3- 1DESIGN METHODOLOGY FLOWCHART SHOWING THE SEQUENTIAL PHASES FROM
REQUIREMENTS | 44
FIGURE 3- 2HYGIENIC DESIGN PRINCIPLES FOR FOOD-CONTACT COMPONENTS, SHOWING SMOOTH
TRANSITIONS, SELF | 46
FIGURE 3- 3FUNCTIONAL DECOMPOSITION DIAGRAM SHOWING THE FOUR PRIMARY SUBSYSTEMS
AND THEIR INTERACTIONS | 49
FIGURE 3- 4SERVO MOTOR AND PLANETARY GEARBOX ASSEMBLY SHOWING ENCODER FEEDBACK,
DRIVE | 52
FIGURE 3- 5DOSING SYSTEM CAD | 52
FIGURE 3- 6PACKAGING AND SEALING SYSTEM CAD | 54
FIGURE 3- 7GENERAL CONTROL SYSTEM ARCHITECTURE BLOCK DIAGRAM SHOWING THE MASTER
ESP32, SLAVE ESP32 | 57
FIGURE 3- 8CLOSED-LOOP THERMAL CONTROL SYSTEM MODELING IN SIMULINK/SIMSCAPE | 59
FIGURE 3- 9PCB LAYER STACK-UP AND GROUNDING STRATEGY | 69

x

FIGURE 4- 1EXPERIMENTAL VALUE | 75
FIGURE 4- 2 SINGLE-LINE DIAGRAM WITH PROTECTION COORDINATION | 93
FIGURE 4- 3 EXPERIMENTAL CLOSED-LOOP RESPONSE USED FOR SYSTEM IDENTIFICATION | 96
FIGURE 5- 1MESH CONFIGURATION IN SOLIDWORKS | 102
FIGURE 5- 2 MESH TYPE (COARSE IN SOLIDWORKS | FIGURE 5- 3MESH TYPE
(FINE IN SOLIDWORKS) | 104
FIGURE 5- 4MESH TYPE (FINE IN ANSYS) | 104
FIGURE 5- 5SOLIDWORKS - HOPPER VON MISES STRESS DISTRIBUTION | 106
FIGURE 5- 6ANSYS_ AUGER VON MISES STRESS DISTRIBUTION | 106
FIGURE 5- 7SOLIDWORKS_ AUGER AND SHAFT VON MISES STRESS DISTRIBUTION | 107
FIGURE 5- 8SOLIDWORKS_ AUGER, SHAFT , AND SPINNER PLATE VON MISES STRESS DISTRIBUTION
| 107
FIGURE 5- 9ES AND CONNECTIONS VON MISES STRESS DISTRIBUTION | 108
FIGURE 5- 10ANSYS_ LONG BLADE VON MISES STRESS DISTRIBUTION\ | 108
FIGURE 5- 11ANSYS_ SHORT BLADE VON_MISES | 109
FIGURE 5- 12VON MISES STRESS DISTRIBUTION IN HORIZONTAL SEALING MECHANISM | 109
FIGURE 5- 13VON MISES, STRAIN DISTRIBUTION, DISPLACEMENT DISTRIBUTION STRESS DISTRIBUTION
IN VERTICAL | 110
FIGURE 5- 14APPLIED LOAD AND FIXED SUPPORTS | 110
FIGURE 5- 15VON MISES STRESS DISTRIBUTION SHOWING MAXIMUM STRESS CONCENTRATION AT
THE JOINTS | 111
FIGURE 5- 16SOLIDWORKS - HOPPER TOTAL DEFORMATION | 112
FIGURE 5- 17ANSYS_ AUGER TOTAL DEFORMATION | 112
FIGURE 5- 18SOLIDWORKS - AUGER+SHAFT TOTAL DEFORMATION | 112
FIGURE 5- 19SOLIDWORKS - AUGER+SHAFT+ PLATE TOTAL DEFORMATION | 113
FIGURE 5- 20SOLIDWORKS - BLADES TOTAL DEFORMATION | 113
FIGURE 5- 21ANSYS_ LONG BLADE TOTAL DEFORMATION | 114
FIGURE 5- 22ANSYS_ SORT BLADE TOTAL DEFORMATION | 114
FIGURE 5- 23STRAIN DISTRIBUTION AND DISPLACEMENT DISTRIBUTION IN HORIZONTAL SEALING
MECHANISM | 115
FIGURE 5- 24VON MISES, STRAIN, DISPLACEMENT DISTRIBUTION STRESS DISTRIBUTION IN VERTICAL
SEALING MECHANISM | 115
FIGURE 5- 25SPLACEMENT CONCENTRATION AT THE JOINTS | 116
FIGURE 5- 26EDEM MATERIAL PROPERTIES CONFIGURATION FOR NACL AND SS304 EQUIPMENT.....118
FIGURE 5- 27AGITATOR TORQUE ANALYSIS TIME-DOMAIN RESULT | 118
FIGURE 5- 28EDEM - AUGER SCREW TORQUE ANALYSIS TIME-DOMAIN RESULTS | 119
FIGURE 5- 29EDEM - CORRELATION PLOT OF ANALYTICAL VS. SIMULATED DOSE MASS | 120
FIGURE 5- 30MOTION SIMULATION TRAJECTORY PLOT SHOWING OPPOSITE ROTATIONAL PATHS OF
THE AGITATOR (CCW) | 121
FIGURE 5- 31 CLOSED-LOOP PID RESPONSE GRAPH | 123
FIGURE 5- 32SCREENSHOT OF THE WOKWI ESP-IDF ENVIRONMENT SHOWING THE TERMINAL OUTPUT
AND MOCK SENSOR RESPONSE TO THE PID | 124
FIGURE 5- 33PERATIONAL TIMING DIAGRAM | 125

## List Of Tables:

TABLE 2- 1 COMPARATIVE ANALYSIS OF VOLUMETRIC AND GRAVIMETRIC DOSING TECHNOLOGIES.... 19
TABLE 2- 2ADVANTAGES AND LIMITATIONS OF VOLUMETRIC VS. GRAVIMETRIC DOSING | 19

xi

TABLE 2- 3 COMPARISON OF STAINLESS STEEL GRADES FOR FOOD-GRADE AUGER APPLICATIONS ...... 29
TABLE 2- 4COMPARATIVE ANALYSIS OF PRESENT WORK AGAINST LITERATURE | 40
TABLE 3- 1FINAL HOPPER DESIGN DIMENSIONS | 52
TABLE 3- 2 SUMMARY OF DESIGN SPECIFICATIONS | 61
TABLE 3- 3 OPERATING PARAMETERS FOR PC817 OPTOCOUPLER IN SENSOR INTERFACE APPLICATIONS
| 62
TABLE 3- 4 MAX6675 SPI INTERFACE PIN ASSIGNMENT | 64
TABLE 3- 5TIP122 SOLENOID DRIVER OPERATING PARAMETERS | 65
TABLE 3- 6 A4988 STEPPER DRIVER CONFIGURATION | 66
TABLE 3- 7 PCB TRACE WIDTH SPECIFICATIONS | 67
TABLE 3- 8 SYSTEM POWER BUDGET ANALYSIS | 69
TABLE 3- 9 VFFS PNEUMATIC SETTINGS FOR DIFFERENT MATERIALS | 70
TABLE 3- 10 PROTECTION COMPONENT SUMMARY | 70
TABLE 4- 1 AUGER DESIGN PARAMETERS BY PRODUCT TYPE | 79
TABLE 4- 2 FILLING ACCURACY REQUIREMENTS | 79
TABLE 4- 3 TORQUE REQUIREMENT CALCULATION | 87
TABLE 4- 4 PANASONIC MSMF042L1U1 | 88
TABLE 4- 5 PANASONIC MBDLN25SE | 89
TABLE 4- 6 CONTROL SIGNAL MAPPING | 89
TABLE 4- 7 COMPLETE ELECTRICAL LOAD INVENTORY | 92
TABLE 4- 8 PROTECTION DEVICE CHARACTERISTICS | 93
TABLE 4- 9 SUMMARY OF ANALYTICAL RESULTS | 94
TABLE 4- 10 OPERATIONAL TIMING SEQUENCE FOR A SINGLE 500G CYCLE | 97
TABLE 4- 11 CONSOLIDATES THE KEY ANALYTICAL PREDICTIONS FOR THE VFFS AUGER FILLING SYSTEM
OPERATING AT A DESIGN THROU | 98
TABLE 5- 1 MESH CONVERGENCE STUDY RESULTS - SOLIDWORKS VS ANSYS | 103
TABLE 5- 2MATERIAL PROPERTIES FOR FEA SIMULATION | 105
TABLE 5- 3COMPREHENSIVE SAFETY FACTOR SUMMARY | 111
TABLE 5- 4 COMPARATIVE DEFLECTION - SHAFT CONFIGURATION STUDY | 116
TABLE 5- 5 LONG AGITATOR BLADE - CROSS-PLATFORM RESULTS | 116
TABLE 5- 6 SHORT AGITATOR BLADE - CROSS-PLATFORM RESULTS | 116
TABLE 5- 7 EDEM MATERIAL PROPERTIES FOR SODIUM CHLORIDE (NACL) | 117
TABLE 5- 8 EDEM PROPERTIES FOR SS304 EQUIPMENT MATERIAL | 117
TABLE 5- 9 EDEM VALIDATION - ANALYTICAL VS. SIMULATION CORRELATION | 120
TABLE 5- 10 MOTION SIMULATION PARAMETERS | 120
TABLE 5- 11 COMPARATIVE LATENCY VALIDATION (DATASHEET VS. SIMULATION) | 124
TABLE 5- 12 FMEA FOR THE VFFS CONTROL SYSTEM VALIDATION | 125
TABLE 5- 13ANALYTICAL VS. NUMERICAL CORRELATION ANALYSIS | 127
TABLE 5- 14 INDUSTRIAL BENCHMARKING COMPARISON | 127
TABLE 5- 15 ACADEMIC AND RESEARCH VALIDATION REFERENCES | 127
TABLE 5- 16 COMPREHENSIVE VALIDATION SUMMARY | 128
TABLE 7- 1: SUMMARY OF OBJECTIVE FULFILLMENT | 148
TABLE 7- 2 COMPREHENSIVE ANALYTICAL–NUMERICAL–TARGET CORRELATION | 149

## CHAPTER ONE

# INTRODUCTION

## INTRODUCTION

### 1.1 Background of the Study

The global packaging industry represents one of the most dynamic and technologically

advanced sectors of modern manufacturing, with an estimated market value exceeding

$1 trillion annually. Within this expansive domain, automated packaging machinery has

emerged as a critical enabler of industrial efficiency, product safety, and supply chain

optimization. The Vertical Form-Fill-Seal (VFFS) machine, first conceptualized in the

mid-20th century, has evolved from simple mechanical devices into sophisticated

mechatronic systems capable of achieving production rates exceeding 200 packages

per minute while maintaining precise weight tolerances of less than one percent [1].

This graduation project addresses the design, analysis, and development of a VFFS

packaging system specifically engineered for the precision dosing of granular and

powdered materials, with particular emphasis on sodium chloride (table salt)

packaging. Table salt was deliberately selected as the target material due to its unique

engineering challenges; its abrasive nature, moisture-dependent bulk density variations,

and free-flowing characteristics make it an optimal candidate for rigorous mechatronic

system validation and performance benchmarking. The project integrates mechanical

engineering principles, bulk solids mechanics, control systems theory, and modern

simulation techniques to deliver a comprehensive engineering solution that meets

contemporary industrial standards for accuracy, reliability, and hygienic compliance.

### 1.1.1 Evolution of Packaging Automation

The historical trajectory of packaging automation reflects broader patterns of industrial

development, from the mechanization of the 19th century through the digital revolution

of the late 20th and early 21st centuries. Early packaging operations were entirely

manual, relying on human labor for filling, sealing, and labeling operations. The

introduction of semi-automatic filling machines in the 1930s marked the first

significant departure from manual methods, though these early devices offered limited

throughput and minimal process control [2].

The post-World War II era witnessed accelerated development in packaging machinery,

driven by rising consumer demand and the expansion of mass retail distribution. The

invention of the form-fill-seal concept by Walter Zwoyer in the 1930s, later refined and

commercialized by companies such as Hayssen and Bosch, established the fundamental operating principles that continue to govern modern VFFS systems. These early

machines employed mechanical cams, gears, and linkages to coordinate the sequential

operations of film transport, forming, filling, and sealing [3].

The digital revolution of the 1980s and 1990s transformed VFFS technology through

the integration of programmable logic controllers (PLCs), servo motor drives, and

electronic sensors. This transition from purely mechanical to electromechanical

systems enabled unprecedented levels of precision, flexibility, and diagnostic

capability. Contemporary VFFS machines incorporate advanced motion control

algorithms, real-time process monitoring, and network connectivity, establishing the

foundation for Industry 4.0 integration [4].

### 1.1.2 Role of VFFS Systems in Global Supply Chains

Vertical Form-Fill-Seal machines occupy a strategically significant position within

global food and consumer goods supply chains. Their compact footprint, high

operational speed, and adaptability to diverse product specifications make them the

preferred packaging solution for granular and powdered commodities including food

products, pharmaceuticals, chemicals, and agricultural materials. Industry estimates

indicate that VFFS systems account for approximately 35% of all flexible packaging

operations worldwide [5].

The economic significance of VFFS technology extends beyond direct equipment sales

to encompass substantial operational savings through reduced labor requirements,

minimized material waste, and enhanced product protection. Modern VFFS systems

achieve material utilization rates exceeding 95% through precise film tracking and

optimized bag forming geometry, contributing to both economic efficiency and

environmental sustainability objectives [6].

Furthermore, the hygienic design principles incorporated into contemporary VFFS

machinery address increasingly stringent food safety regulations, including FDA

requirements in the United States and EU hygiene standards in Europe. Stainless steel

construction, smooth surface finishes, and clean-in-place (CIP) capabilities ensure

compliance with Good Manufacturing Practice (GMP) guidelines essential for food-

grade packaging operations [7].

### 1.1.3 Precision Dosing: The Critical Role of Auger Fillers

Among the various dosing mechanisms employed in VFFS applications, auger filling

systems represent the most widely adopted technology for granular and powdered

materials. The auger filler operates on the principle of positive displacement, wherein

a rotating helical screw (auger) within a cylindrical housing transports material from a

supply hopper to a discharge point. The volumetric displacement per revolution is

determined by the auger geometry, enabling precise control of dispensed quantity

through accurate angular positioning [8].

The fundamental relationship governing auger filling performance derives from the

geometric displacement of the helical screw:

Vtℎ = (π/4) × (D² − D_s²) × P | (1.1)

Where Vtℎ represents the theoretical volumetric displacement per revolution, D is the

outer diameter of the auger flight, D_s is the shaft diameter, and P is the pitch of the

helical flight. This geometric relationship, first systematically analyzed by Roberts and

Rademacher in the context of screw conveyor theory, provides the theoretical

foundation for auger design and performance prediction [9].

However, the practical implementation of auger filling involves significant deviations

from ideal theoretical behavior due to the complex mechanical properties of bulk solids.

Factors including particle size distribution, bulk density variation, interparticle friction,

cohesive forces, and wall friction effects all contribute to the difference between

theoretical and actual volumetric efficiency. Empirical studies indicate that typical

volumetric efficiency factors range from 0.4 to 0.9, depending on material properties

and operating conditions [10].

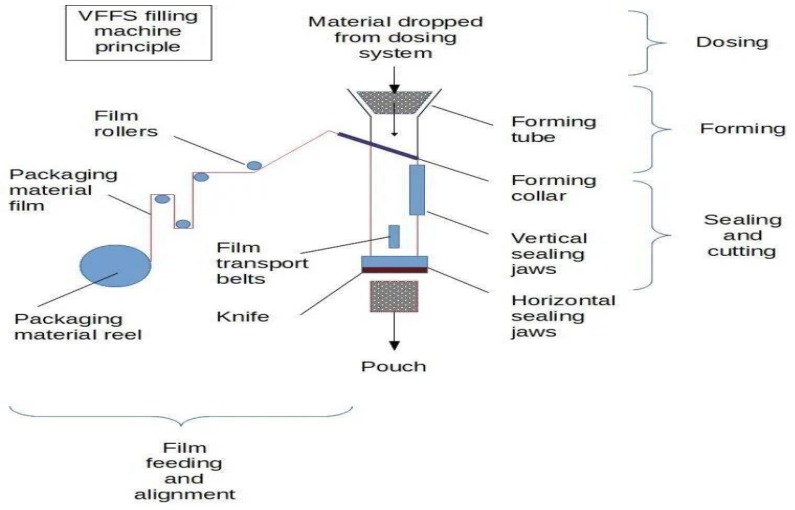
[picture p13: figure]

Figure 1- 1 Schematic illustration of VFFS machine with integrated auger filling system

### 1.2 Problem Statement

Despite the widespread adoption of VFFS technology in industrial packaging

applications, several persistent challenges limit the achievement of optimal

performance in powder and granular material handling. These challenges span

mechanical design, process control, and operational reliability domains, creating

opportunities for significant engineering improvement through systematic research and

development.

### 1.2.1 Inaccuracy and Inconsistency in Powder Filling

The primary performance metric for any filling system is dosing accuracy, typically

expressed as the percentage deviation between target and actual dispensed mass. For

commercial packaging operations, regulatory standards such as OIML R87 specify

maximum permissible errors based on package weight, with stricter tolerances applied

to smaller packages. For a 500g package of salt, the maximum permissible error is

typically ±1.5%, corresponding to ±7.5g [11].

Achieving consistent accuracy in auger filling is complicated by several factors

inherent to bulk solid behavior. Bulk density variation, resulting from changes in

material consolidation, moisture content, or particle packing arrangement, directly

affects the mass-to volume conversion that underlies volumetric dosing principles.

Studies have demonstrated that bulk density of granular salt can vary by ±5-10% under

normal operating conditions, creating corresponding variations in dispensed mass

unless compensated through control system intervention [12].

Additional sources of dosing error include:

- Slip between material and auger flight surfaces, reducing effective

displacement;

- Backflow through radial clearance between flight tip and housing wall;
- Incomplete filling of auger flights due to hopper flow irregularities;
- In-flight material continuing to fall after motor stop command;
- Kinematic inertia causing continued rotation during deceleration phases.

The cumulative effect of these error sources can result in total dosing errors exceeding

acceptable limits unless addressed through integrated mechanical and control system

design.

### 1.2.2 Structural and Thermal Challenges in Continuous Operation

Industrial VFFS machines are typically required to operate continuously for extended

periods, often exceeding eight hours per shift under demanding production schedules.

This operational intensity imposes significant mechanical and thermal loads on critical

components, particularly the auger drive system and sealing mechanisms.

The auger shaft experiences substantial torsional loading during operation, particularly

during startup when breakaway torque is required to initiate motion of compacted

material. Analytical calculations for the proposed design indicate maximum torque

requirements of approximately 20 N·m under worst-case conditions. The shaft must

withstand these loads without excessive deflection that would compromise the critical

radial clearance between rotating and stationary components [13].

Thermal considerations arise from multiple sources including motor heating, friction at

bearing surfaces, and heat transfer from the sealing jaws. The sealing operation for

plastic films typically requires temperatures of 150-200°C, creating thermal gradients

that can affect component dimensions and material properties. Thermal expansion of

the auger shaft, if not properly accommodated, can result in binding or increased

friction within the dosing chamber [14].

### 1.2.3 Limitations of Conventional Empirical Design Methods

Traditional approaches to auger filler design have relied heavily on empirical

correlations and industry rules of thumb developed through decades of practical

experience. While these methods have proven effective for conventional applications,

they exhibit significant limitations when applied to novel materials, non-standard

operating conditions, or precision requirements exceeding typical industrial norms.

The Conveyor Equipment Manufacturers Association (CEMA) provides standardized

design equations for screw conveyors, but these formulations were developed for bulk

material transport rather than precision dosing applications. The translation from

continuous conveying to discrete volumetric metering introduces additional complexity

not fully addressed by conventional design methodologies [15].

Furthermore, empirical design approaches provide limited insight into the underlying

physical phenomena governing system behavior. Without fundamental understanding

of powder flow mechanics, stress distribution, and dynamic response, optimization of

design parameters becomes a trial-and-error process rather than a systematic

engineering exercise. This project addresses this gap through the integration of

analytical modeling, numerical simulation, and experimental validation methodologies.

### 1.2.4 Control System Latency and Electromechanical Synchronization

Beyond mechanical and thermal constraints, a critical challenge in VFFS operations

lies in the mechatronic synchronization between the dispensing mechanism and the

sealing actuation. Traditional systems often suffer from control latency and sensor

feedback delays, leading to the 'dribble effect'—where residual powder falls into the

seal area during jaw closure, compromising package integrity. Achieving precise, real-

time coordination requires an advanced control architecture capable of microsecond-

level execution. This necessitates the transition from conventional empirical timing to

highly responsive, microcontrollerdriven motion profiling to seamlessly synchronize

servo-actuated dosing with the kinematic cycle of the packaging process.

### 1.3 Aim and Objectives

The overarching aim of this graduation project is to design, analyze, and validate a

complete VFFS packaging system with integrated auger filler specifically optimized

for the precision packaging of granular sodium chloride. The project encompasses mechanical design, control system development, and comprehensive performance

validation through analytical and numerical methods.

The specific objectives of the project are:

1. To develop a comprehensive understanding of bulk solids mechanics and

powder flow behavior as applied to auger filling systems, including the

characterization of material properties affecting dosing accuracy.

2. To design the mechanical architecture of a VFFS auger filling system,

including auger geometry, drive train specification, hopper configuration,

and flow control mechanisms, meeting industrial standards for hygiene and

reliability.

3. To establish analytical models for volumetric displacement, torque

requirements, and structural loading, enabling quantitative prediction of

system performance.

4. To perform Multiphysics numerical simulations including static structural

analysis, thermal analysis, and modal analysis to validate mechanical design

decisions and identify potential failure modes.

5. To develop control system architecture incorporating servo motor

positioning, sensor integration, and feedback algorithms to achieve target

dosing accuracy of ±1.5% for 500g packages.

6. To correlate analytical predictions with numerical simulation results,

establishing confidence in the design methodology and identifying areas

requiring refinement.

### 1.4 Research Questions

This project addresses the following research questions that guide the investigation and

provide focus for the engineering analysis:

RQ1.What auger geometry (outer diameter, shaft diameter, pitch, and flight profile)

optimizes the trade-off between volumetric displacement capacity and

mechanical stress distribution for the target 500g dose requirement?

RQ2.How do bulk density variations and powder flow properties affect dosing

accuracy, and what control strategies can compensate for these variations in

real-time operation?

RQ3.What are the critical structural loading conditions for the auger shaft and drive

train, and what safety factors ensure reliable operation under worst-case

scenarios including material caking and startup conditions?

RQ4.How does thermal expansion from sealing jaw heating affect component

clearances and dosing accuracy, and what design measures mitigate thermal

effects?

RQ5.What is the correlation between analytical predictions and numerical simulation results, and how do deviations inform design refinement decisions?

### 1.5 Scope and Limitations

The scope of this graduation project encompasses the complete engineering design and

analysis of a VFFS auger filling system, with specific boundaries defining the extent of

investigation and areas explicitly excluded from consideration.

### 1.5.1 Scope of Work

The project scope includes:

- Mechanical design of auger screw, central shaft, spinner plate, and associated

tooling;

- Specification and selection of servo motor, gearbox, and drive train

components;

- Design of hopper and agitator system for consistent material feeding;
- Development of a centralized mechatronic control architecture utilizing

advanced microcontrollers (ESP32) for precise servo motion profiling, real-

time synchronization, PID-based thermal control of sealing jaws, and

comprehensive sensor data fusion;

- Analytical modeling of volumetric displacement, torque, and power

requirements;

- Finite Element Analysis (FEA) of structural, thermal, and modal behavior;
- Validation of design through correlation between analytical and numerical

results.

### 1.5.2 Limitations

The following aspects are explicitly outside the scope of this project:

- Physical prototype fabrication and experimental testing (the project is limited to

design and simulation phases);

- Economic analysis, cost estimation, and market feasibility studies;
- Investigation of alternative dosing technologies (cup fillers, weigh fillers, etc.);
- Long-term reliability testing and wear analysis under extended operation.

The target material is limited to granular sodium chloride (table salt) with specified

particle size distribution and moisture content. While the design principles may be

applicable to other granular materials, validation is specifically performed for salt

packaging applications.

### 1.6 Significance of the Study

This graduation project contributes to engineering knowledge and industrial practice

through multiple pathways of significance:

### 1.6.1 Academic Contribution

The project demonstrates the integration of multiple engineering disciplines—

mechanical design, bulk solids mechanics, control systems, and numerical

simulation— within a unified design framework. The systematic correlation between

analytical models and finite element analysis provides a methodology applicable to

similar mechatronic system development. Furthermore, the detailed treatment of

powder flow phenomena augments the existing literature on auger filling technology,

which has historically received less scholarly attention than other bulk material

handling systems [16].

### 1.6.2 Industrial Relevance

The design outcomes directly address industrial requirements for high-speed, accurate,

and reliable powder packaging. The target specifications—500g packages at 20 bags

per minute with ±1.5% accuracy—represent typical production requirements for

medium-scale food packaging operations. The methodology employed, combining

theoretical analysis with simulation validation, offers a template for systematic design

optimization that can reduce development time and prototyping costs [17].

### 1.6.3 Technological Innovation

The integration of advanced servo control with mechanical flow control mechanisms

(spinner plate) represents an innovative approach to addressing the persistent challenge of dribble elimination in free-flowing granular materials. The dual-core ESP32 control

architecture with distributed processing of motion control and thermal management

tasks demonstrates the application of modern embedded systems technology to

packaging machinery [18].

### 1.7 Methodology Overview

The project follows a systematic engineering design methodology progressing from

requirements definition through conceptual design, detailed analysis, and validation.

The overall approach integrates analytical modeling, computational simulation, and

design verification in an iterative framework.

### 1.7.1 Research Design Framework

The methodology adopts a mixed-methods approach combining theoretical analysis,

numerical simulation, and design validation. The research design follows the classical

engineering method: problem definition, background research, conceptual design,

detailed analysis, and verification. This structured approach ensures comprehensive

coverage of all technical aspects while maintaining traceability from requirements to

final design [19].

### 1.7.2 Mechatronic System Design Phase

Following the conceptualization, the detailed physical and electronic architecture is

developed. This phase encompasses:

- Mechanical CAD Modeling: Generating detailed 3D models of the auger,

hopper, drive train, and support structures using parametric CAD software (e.g.,

SOLIDWORKS) to ensure spatial integration and manufacturability;

- Electrical & Control Architecture: Selecting the appropriate sensors, actuators

(servo motors), and microcontroller units (e.g., ESP32), accompanied by

developing the wiring schematics and preliminary control logic flowcharts for

the dispensing and sealing synchronization.

### 1.7.3 Analytical Modeling Phase

The analytical phase establishes mathematical models governing system behavior:

- Volumetric displacement theory based on auger geometry and powder

properties;

- Torque and power requirements derived from material resistance and inertial

loading;

- Structural mechanics equations for stress, deflection, and critical speed

analysis;

- Control system models for motion profiling and feedback compensation.

### 1.7.4 Numerical Simulation Phase

Finite Element Analysis (FEA) using SOLIDWORKS Simulation and ANSYS

Mechanical provides detailed insight into:

- Static structural response under maximum torque loading;
- Thermal distribution and expansion effects;
- Modal characteristics and resonance avoidance;
- Motion dynamics and interference validation.

### 1.7.5 Validation and Correlation

The final phase correlates analytical predictions with simulation results, quantifying

deviations and establishing confidence bounds for design decisions. Statistical

comparison of key performance parameters—stress, deflection, torque, and dosing

accuracy—validates the analytical framework and confirms design adequacy.

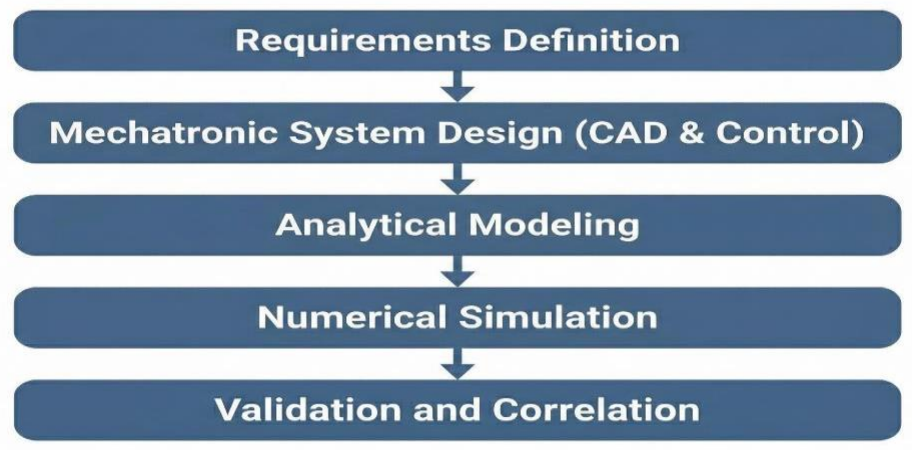
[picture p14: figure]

Figure 1- 2 Project methodology flowchart showing the sequential phases .

### 1.8 Organization of the Report

This graduation project report is organized into seven chapters, each addressing

specific aspects of the design and analysis process:

Chapter One: Introduction presents the background, problem statement, objectives,

research questions, scope, and significance of the study. This chapter establishes the

context and motivation for the project.

Chapter Two: Literature Review provides a comprehensive survey of existing

knowledge in VFFS technology, powder rheology, auger engineering, and Multiphysics

simulation. This chapter identifies the theoretical foundations and research gaps

addressed by the project.

Chapter Three: System Design and Specifications details the design requirements,

conceptual development, and final mechanical architecture. CAD representations and

control system logic are presented in this chapter.

Chapter Four: Analytical Modeling and Calculations presents the mathematical

foundations, kinematic and kinetic models, torque and power estimation, and structural

mechanics equations governing system behavior.

Chapter Five: Multiphysics Simulation and Validation describes the computational

setup, static structural analysis, thermal-structural coupling, modal analysis, and

correlation between analytical and simulation results.

Chapter Six: Results Discussion and Evaluation synthesizes the findings, evaluates

machine performance, discusses mechatronic synergy, and assesses the contribution to

engineering knowledge.

Chapter Seven: Conclusion and Future Work summarizes the key findings, evaluates

objective fulfillment, provides recommendations for prototype fabrication, and suggests

directions for future research including AI/ML integration.

The report also includes comprehensive appendices containing engineering drawings,

control documentation, simulation reports, and detailed calculation spreadsheets.

# CHAPTER TOW

# LITERATURE REVIEW

## LITERATURE REVIEW

The development of automated packaging systems for powdered materials represents a sophisticated convergence of mechanical design, granular mechanics, and mechatronic control engineering. This chapter presents a critical review of the fundamental engineering principles and state-of-the-art advancements in Vertical Form-Fill-Seal (VFFS) technology and auger-driven dosing mechanisms, establishing the theoretical foundation for the mechatronic system developed in this project.

### 2.1 VFFS and Dosing Technologies

Vertical Form Fill Seal (VFFS) technology represents a cornerstone in modern automated packaging, particularly for granular, powdered, and liquid products. Its efficiency stems from the integrated process of forming a bag from a roll of film, filling it with the product, and then sealing it, all within a continuous vertical motion. The efficacy of a VFFS system is intrinsically linked to the precision and reliability of its dosing mechanism, which dictates product consistency and economic viability. This section delineates the operational principles of VFFS machines and provides a comparative analysis of volumetric versus gravimetric dosing technologies, highlighting their respective advantages, limitations, and suitability for various industrial applications.

### 2.1.1 Operating Principles of Vertical Form Fill Seal Machines

The Vertical Form-Fill-Seal (VFFS) machine constitutes a cornerstone technology in modern automated packaging, integrating three distinct yet kinematically synchronized operations forming, filling, and sealing into a single continuous production cycle [1]. Since its commercial introduction in the mid-20th century, VFFS technology has evolved from simple mechanical cam-driven systems to sophisticated mechatronic architectures incorporating advanced servo control, real-time process monitoring, and adaptive adjustment capabilities [2].

- Kinematic Sequence and Film Handling

The operational sequence of a VFFS system initiates with the tension-controlled unwinding of flexible packaging film from a supply reel. The film web is drawn through the machine via motor-driven friction belts or vacuum pull mechanisms, with precise tension regulation maintained through dancer roller assemblies and electronic feedback systems to prevent wrinkles, stretching, or misalignment that would compromise package integrity [3]. The film subsequently passes over a forming collar (forming shoulder), a geometrically optimized component that transforms the two-dimensional web into a cylindrical configuration around the central forming tube. The design of the forming collar particularly its bending angles and surface curvature requires precise reverse engineering to minimize film stress and ensure consistent bag geometry [4].

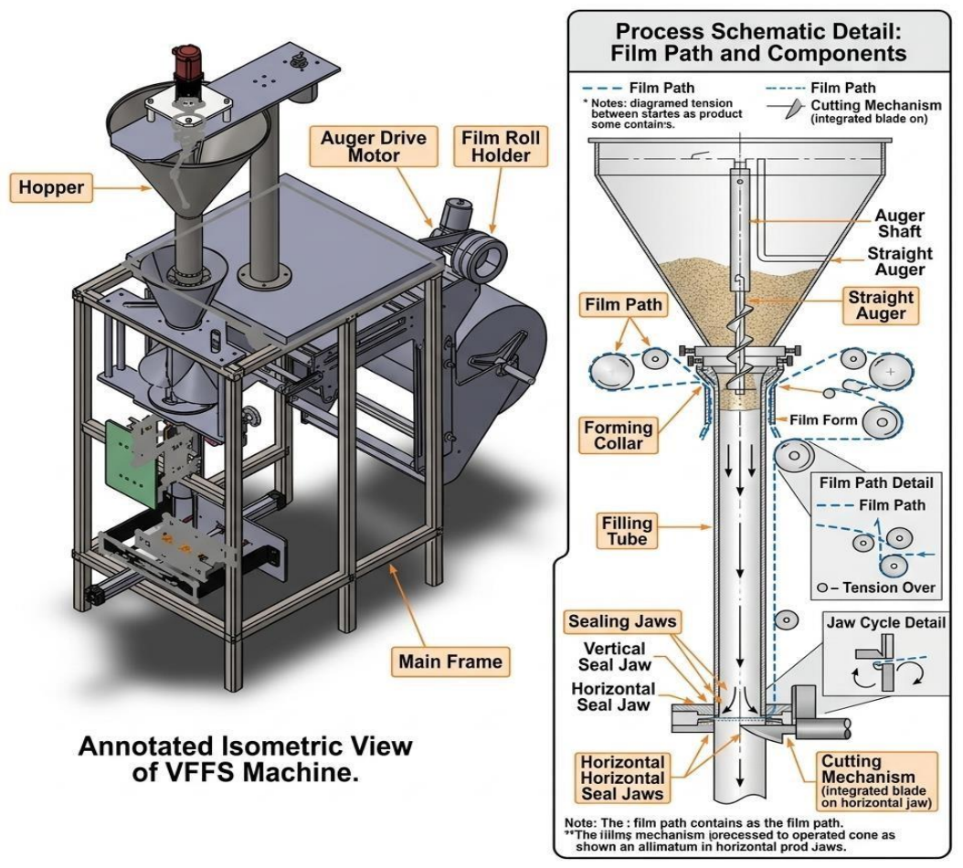
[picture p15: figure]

Figure 2- 1 Schematic representation of the Vertical Form-Fill-Seal (VFFS) operational cycle.

Upon formation of the cylindrical tube, a longitudinal sealing jaw creates a continuous vertical seam (overlap or fin seal), while the horizontal cross-sealing jaws execute two simultaneous functions: forming the bottom seal of the current bag and the top seal of the preceding bag. The sealing operation involves precise thermodynamic control of temperature, pressure, and dwell time to achieve hermetic seals without thermal degradation of the film [5].

Furthermore, precise web tracking is continuously monitored and corrected by photoelectric edge-guide sensors to prevent lateral drift during high-speed unwinding. Following the crosssealing phase, an integrated mechanical or pneumatic guillotine separates the continuous web into individual packages accommodating various geometries such as standard pillow bags, gusseted bags, or block-bottom pouches which are subsequently discharged onto synchronized conveyors for secondary packaging operations.

- Critical Synchronization Requirements

The efficiency of the VFFS process is fundamentally governed by the synchronization between the film transport mechanism and the dosing unit. The "Filling Window" defined as the strict temporal interval during which the product must be completely discharged into the formed tube without contaminating the horizontal seal area represents the primary kinematic constraint in high-speed applications. In modern industrial systems operating at cycle times below 2.0 seconds, this synchronization necessitates the replacement of traditional mechanical clutches with high-precision AC Servo motors, enabling millisecond-accurate control over film pull-rate and dwell time while eliminating inertial errors associated with mechanical indexing [6]. This mechatronic evolution is particularly critical for handling abrasive or hygroscopic materials such as Sodium Chloride (NaCl), where misalignment between the dosing pulse termination and jaw opening results in "product-in-seal" contamination and package rejection [7].
- Motion Architecture: Intermittent vs. Continuous
Contemporary VFFS systems employ two distinct motion architectures. Intermittent motion systems, characterized by discrete stopping periods for filling and sealing operations, offer superior precision for applications requiring gravimetric verification but limit maximum throughput. Continuous motion systems, wherein sealing jaws track the moving film during the sealing cycle, achieve higher production rates (exceeding 12 packs per minute) but demand complex control algorithms for maintaining seal integrity during relative motion [8]. The selection between these architectures involves trade-offs between speed, precision, and mechanical complexity, with intermittent systems predominating in applications requiring high dosing accuracy.

### 2.1.2 Volumetric vs. Gravimetric Dosing: A Comparative Analysis

The dosing unit constitutes the critical precision determining subsystem within the VFFS architecture. In industrial bulk solids handling, two fundamental technical philosophies govern product metering: gravimetric dosing, which measures mass directly, and volumetric dosing, which measures geometric displacement. The selection between these methodologies represents a strategic engineering decision based on the trade-off between throughput speed (Packs Per Minute, PPM) and absolute mass accuracy (±σ) [9].

While volumetric metering encompasses various mechanisms including cup fillers for freeflowing solids and piston fillers for viscous liquids the vertical auger filler remains the predominant standard for powdered and granular materials. Conversely, gravimetric systems, primarily realized through linear scales and multi head weighers, offer significant economic advantages by drastically minimizing "product give-away" (overfilling). This reduction in material waste is highly desirable for expensive commodities, albeit achieved at the cost of increased mechanical complexity and reduced maximum throughput.

- Gravimetric Dosing (Weight-Based Systems)

Gravimetric dosing systems employ high-precision load cells to measure product mass directly, either through checkweighing of completed packages or net-weight control during the filling process. The fundamental advantage of this approach lies in its independence from material bulk density variation, enabling consistent achievement of ( 0.1% − 0.5% ) accuracy regardless of changes in material compaction, moisture content, or particle size distribution [10].

Advanced gravimetric implementations utilize two speed filling strategies (bulk and dribble/drip phases): rapid dispensing to a predetermined threshold (typically 90-95% of target mass), followed by slow, controlled filling to the final target weight. However, gravimetric systems are inherently constrained by the mechanical settling time required for load cell signal stabilization and the associated control system latency. These dynamic limitations render purely gravimetric systems unsuitable for high-speed VFFS lines operating at cycle times below 3.0 seconds, where the stabilization delay creates a severe production bottleneck [11]. Additionally, the complexity of load cell integration, calibration requirements, and environmental vibration isolation increases both initial capital cost and ongoing maintenance demands [12].

- Volumetric Dosing (Auger Filling Systems)

Volumetric dosing systems, predominantly realized through vertical Archimedean screw (auger) mechanisms, operate on the principle of geometric displacement. The system assumes that each revolution of the helical auger displaces a constant, mathematically defined volume of material. The theoretical mass delivered per revolution (mrev) is determined by the product of the effective flight volume (Veff) and the operational bulk density (ρv):

mrev = Veff × ρv = nv ×

π
4

× (D

2 − Ds

2
) × P × ρv | (2.1)
- Comparative Summary and Hybrid Approaches

Where nv represents the volumetric efficiency, D the auger outer diameter, Ds the shaft diameter, and P the pitch [13].

The primary advantages of auger filling include exceptional kinematic speed (achieving up to more than 120 PPM), mechanical simplicity with minimal moving parts, continuous flow control through direct servo motor coupling, and hygienic design suitable for food-grade applications. The direct coupling of the auger shaft to high-torque servo motors enables precise angular displacement control (θ)with instantaneous start-stop functionality, eliminating the latency inherent in weight-based measurement systems [14].

However, the critical vulnerability of volumetric dosing lies in its fundamental assumption of bulk density constancy. For granular materials such as Sodium Chloride (ρv ≈ 1300 kg
m³

), aeration during hopper discharge, vibration-induced compaction, and particle segregation can cause density fluctuations of ±5 − 10%directly propagating to mass dosing errors. This "mass-drift" phenomenon, extensively documented in powder handling literature, historically limited volumetric system accuracy to ±0.5 − 2.0% without external compensation [15].

Table 2- 1 Comparative Analysis of Volumetric and Gravimetric Dosing Technologies

Characteristic | Volumetric (Auger) | Gravimetric (Net-Weigh)
Operating Principle | Geometric Displacement | Direct Mass Measurement
Accuracy | ±0.5 − 2.0% (density-dependent) | 0.1% − 0.5% (absolute)
Throughput | High (up to 150 PPM) | Moderate (up to 40 PPM)
Density Sensitivity | High | None
Initial Cost | Lower | Higher
Maintenance Complexity | Low (minimal moving parts) | High (load cell calibration)
Material Suitability | Free-flowing powders & granules | Variable density materials, precision chemicals
Control Architecture | Open-loop or compensated closed-loop | Inherent closed-loop feedback

Table 2- 2Advantages and Limitations of Volumetric vs. Gravimetric Dosing

Dosing
Technology
Advantages | Limitations (Disadvantages)

Volumetric
Dosing (e.g.,
Auger Fillers)
- High Speed: Achieves very high production rates due to continuous operation and simple control logic.
- Cost-Effective: Lower initial capital and maintenance costs, ideal for high-volume/lower-value products.
- Simplicity: Straightforward operational principle requiring less complex calibration for materials with stable density.
- Bulk Density Dependence: Highly susceptible to variations in material compaction, particle size, and moisture.
- Limited Accuracy: Potential weight inaccuracies make it unsuitable for products with fluctuating densities or strict weight requirements.

Recent advancements in mechatronic engineering have addressed the traditional speedaccuracy trade-off through hybrid dosing strategies. Rather than replacing the mechanical auger, modern systems upgrade the control layer through the integration of adaptive microcontrollers (such as ESP32 architectures) implementing real-time "Volumetric Correction Factors." By periodically calibrating bulk density via offline sampling or integrating closed-loop feedback from auxiliary load cells, these systems dynamically adjust the required number of motor revolutions (Nreq), effectively synthesizing the speed advantages of volumetric filling with the accuracy characteristics of gravimetric measurement [16].

The "Bulk and Trim" filling strategy represents a particularly effective hybrid approach: the auger operates at high speed to dispense 90 − 95% of the target mass (volumetric mode), subsequently reducing to low speed for final weight adjustment based on instantaneous feedback from a load cell (gravimetric mode). This mechatronic integration enables achievement of high production throughput (30-35 bags/minute) while maintaining strict accuracy tolerances of ±1.5%, bridging the historical gap between volumetric speed and gravimetric precision [17].

- Justification for Volumetric Auger Selection in This Project

For the current application targeting 500g salt packages at 20 bags per minute with 1.5% accuracy, the volumetric auger filler with servo motor control and density compensation represents the optimal engineering solution. This selection is justified by: (1) the relatively consistent bulk density of crystalline Sodium Chloride; (2) the moderate speed requirements that align with volumetric system capabilities; (3) the lower capital and maintenance costs compared to gravimetric alternatives; (4) the mechanical compatibility with VFFS architecture; and (5) the demonstrated effectiveness of microcontroller-based

Gravimetric
Dosing (e.g.,
Multi-head
Weighers)
- High Accuracy: Measures
mass directly, making it
completely independent of bulk density variations.
- Versatility: Highly precise for a wide range of materials, including those with irregular shapes or fragile compositions.
- Reduced Product Give-Away: Minimizes overfilling, leading to significant long-term cost savings for high-value products.
- Lower Speed: Generally slower due to the mechanical settling time required for weighing and
stabilization.
- Higher Cost: More expensive to acquire and maintain due to complex load cells and control algorithms.
- High Complexity: Demands sophisticated calibration, regular maintenance, and strict
environmental control (e.g., vibration isolation).

compensation algorithms in addressing density-induced errors without sacrificing throughput [18].

### 2.2 Powder Rheology and Handling

The design of high-precision mechatronic dosing systems necessitates a profound understanding of bulk solids mechanics a field that diverges fundamentally from both Newtonian fluid dynamics and continuum solid mechanics. Unlike fluids, powders and granular materials exhibit yield strength and can sustain shear stresses when at rest; unlike continuous solids, they flow plastically when subjected to stresses exceeding their yield locus, transmitting forces through complex inter-particle contact networks rather than continuous strain fields [19]. This dual nature, characterized by the coexistence of solid-like and fluid-like behaviors, renders classical hydrodynamic and electrostatic analyses inadequate for predicting powder flow phenomena.

In the context of Vertical Form-Fill-Seal (VFFS) auger filling systems, the rheological behavior of the target material specifically Sodium Chloride (NaCl) directly governs volumetric efficiency, motor torque requirements, dosing precision, and the susceptibility to flow obstructions. This section establishes the theoretical foundation for powder characterization and analyzes the complex transport dynamics within helical screw conveyors.

### 2.2.1 Material Characteristics: Bulk Density, Flowability, and

Cohesiveness
The successful transport and metering of granular material through an auger system is fundamentally dictated by three primary physicochemical properties: bulk density, flowability, and cohesiveness. These characteristics are not intrinsic material constants but rather emergent behaviors dependent on environmental conditions, stress history, and particle-level interactions.
A. Bulk Density and Compressibility

Bulk density (ρv) is defined as the ratio of powder mass to the total occupied volume, inclusive of interstitial voids between particles:

ρv =

Mpowder

Vtotal

= ρpractical(1 − ε) | (2.2)

where ρv represents the true particle density (approximately 2165 kg/m³ for crystalline NaCl) and ε denotes the void fraction [20]. It is essential to distinguish between true density and operational bulk density: while the former is an intrinsic material property, the latter varies significantly with consolidation stress, vibration, and aeration state.

For granular table salt, operational bulk density typically ranges between 1100 and 1300 kg/m³, with the lower bound corresponding to loosely poured material and the upper bound representing vibrationally consolidated states [21]. This compressibility phenomenon wherein bulk density increases with consolidation pressure and vibration represents the primary source of dosing deviations in volumetric auger systems. The degree of compressibility is quantified through the Hausner Ratio:

HR =

ρtapped

ρbulk

(2.3)

Hausner ratios below 1.2 indicate free-flowing materials, while ratios exceeding 1.4 suggest cohesive, poorly flowing powders. Granular salt typically exhibits Hausner ratios of 1.1
1.2, consistent with its classification as a free-flowing material [22].

The variation in bulk density is not merely a static concern but a dynamic process variable. Within the confines of a VFFS hopper, the material column generates hydrostatic-like pressure that increases consolidation toward the discharge orifice. Furthermore, mechanical vibrations from the auger drive and adjacent machinery induce progressive compaction, altering the mass-to-volume relationship in real-time. This necessitates the integration of mechanical agitation systems to maintain a consistent density regime prior to auger entry, thereby mitigating mass-drift phenomena [23].

B. Cohesiveness and the Mohr-Coulomb Failure Criterion

The stress state within bulk solids is mathematically described using the Mohr-Coulomb yield criterion, which defines the shear stress required to initiate plastic flow:

τ = σ × tan (Q_i ) + c | (2.4)

where τ represents the shear stress at failure, σ is the normal stress, Qi is the angle of internal friction, and c is the cohesion intercept [24]. This framework distinguishes between freeflowing materials (c ≈ 0) and cohesive materials (c > 0).

Dry, crystalline sodium chloride is classified as free-flowing, with internal friction angles ranging between 25° and 35° and negligible cohesion under standard atmospheric conditions [25]. However, NaCl exhibits pronounced hygroscopicity, readily absorbing atmospheric moisture to form liquid bridges between crystals. Upon subsequent drying, these bridges solidify into robust particle-particle bonds, dramatically increasing cohesive forces (c > 0) and necessitating substantially higher shear stresses—and consequently, greater motor torque to overcome flow resistance [26].

The transition from free-flowing to cohesive behavior has profound implications for system design. Cohesive arching (bridging) above the auger intake and ratholing within the hopper represent critical failure modes that disrupt continuous feeding and introduce dosing irregularities. The mechanical design must therefore incorporate sufficient dynamic shearing capability to break cohesive bonds during operation, alongside hopper geometries that promote mass flow (wherein all particles are in simultaneous motion) rather than funnel flow (which creates stagnant zones and erratic density) [27].

C. Flowability and Angle of Repose

Flowability describes the macroscopic response of a powder to applied stress, governed by microscopic particulate interactions. It is quantified through the Flow Function (ffc), defined as the ratio of major consolidation stress (σ1) to unconfined yield strength (σc):

ffc =

σ1
σc

(2.5)

Jenike's classification framework establishes the following criteria: ffc > 10 indicates free-flowing material; 4 < ffc < 10 indicates easy-flowing; 2 < ffc < 4 indicates cohesive; and 1 < ffc < 2 indicates very cohesive or non-flowing behavior [10]. While dry salt typically falls within the free-flowing category ( ffc ≥ 4 ), moisture ingress can degrade it to cohesive states, necessitating continuous monitoring of environmental humidity.

The angle of repose the maximum stable slope angle of a poured powder heap provides an empirical flowability indicator complementary to shear testing. For granular salt, this angle typically ranges between 30° and 45°, with lower values indicating superior flowability [28]. This geometric property is critical for hopper design: wall angles must exceed 60° (significantly steeper than the angle of repose) to enforce mass flow and prevent arching. Furthermore, the angle of repose validates the engineering necessity of the spinner plate (dribble collector) mechanism at the discharge nozzle, which prevents gravitational leakage and uncontrolled flow after auger rotation cessation [29].

D. Janssen's Effect and Pressure Distribution

A fundamental distinction between powder statics and fluid hydrostatics is articulated through Janssen's theory (1895), which demonstrates that vertical pressure within granular columns does not increase linearly with depth. Instead, frictional interaction between the powder and container walls supports a portion of the material weight, causing vertical pressure to asymptotically approach a saturation value:

σv =

ρb×g×D
4μω×K

(1 − e

4μω×K×

h
D) (2.6)

where D is the hopper diameter, μω is the wall friction coefficient, K is the lateral pressure ratio, and h is the fill depth [30]. This pressure saturation ensures that material at the auger intake is not subjected to crushing pressures proportional to total hopper height, thereby preserving particle integrity and flowability.

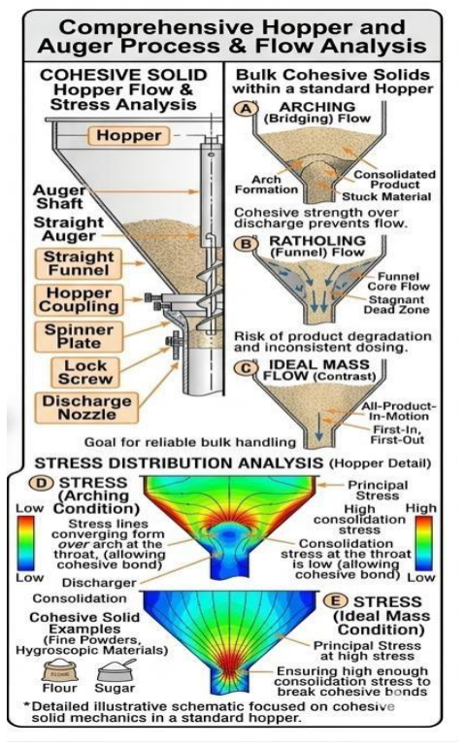
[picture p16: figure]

Figure 2- 2 Stress distribution and characteristic flow behavior of bulk cohesive solids within a standard hopper.

### 2.2.2 Dynamics of Screw-Driven Material Transport

The kinematic transport of granular material through a helical screw represents a complex multiphase flow phenomenon significantly more intricate than the ideal rigid-plug flow model implies. The auger does not function as a positive-displacement pump in the hydraulic sense; rather, axial transport emerges from the tribological interaction between particles, the rotating screw surface, and the stationary casing wall.

I. Tribological Balance and Axial Transport Mechanism

Effective axial conveying depends upon a delicate balance between friction forces acting on particles. For forward transport to occur, the friction force against the stationary wall (Fwall ) must exceed the friction force against the rotating screw surface (Fscrew ). If the material possesses excessive internal friction or adheres preferentially to the screw surface (Fscrew > Fwall ), the powder will rotate as a single rigid body a failure mode termed the "doughnut effect" resulting in complete cessation of axial pumping [31].

This tribological constraint dictates material selection and surface finish specifications for auger components. Highly polished surface finishes (e.g., 2B finish on AISI 316L stainless steel with Ra < 0.5 µm) minimize the wall friction angle (Qω), thereby promoting the differential friction necessary for axial transport while satisfying hygienic requirements for food-contact applications [32].

The theoretical volumetric displacement per revolution is geometrically determined by the screw geometry:

Vtheoretical =

π
4

(D

2 − Ds

2
) × P | (2.7)

where D is the auger outer diameter, d is the shaft diameter, and P is the pitch. However, the actual mass delivered depends on the operational bulk density (ρb) and volumetric efficiency (nv):

mactual = Vtheoretical × ρb × nv | (2.8)
II. | Vortex Motion, Backflow, and Volumetric Efficiency

Advanced computational studies utilizing Discrete Element Method (DEM) simulations have revealed that particles within the screw channel do not follow strictly linear helical paths. Instead, they exhibit complex three-dimensional velocity fields characterized by granular vortex motions localized circulation patterns within individual pitches that consume energy and reduce transport efficiency [33].

A critical volumetric loss mechanism arises from "backflow" through the radial clearance (C) between the flight tip and the casing wall. This backward leakage, wherein material bypasses the advancing flight by flowing through the annular gap, increases proportionally with rotational speed and inversely with particle size relative to clearance dimension. For precision dosing applications, radial clearances must be minimized (typically 1.0–2.0 mm) while maintaining sufficient tolerance to prevent metallic contact and galling [17].

The volumetric efficiency factor (nv)—defined as the ratio of actual to theoretical volumetric displacement encapsulates these non-ideal behaviors:
| nv = Vactual Vtherotical
(2.9)

Empirical observations for well-designed augers handling free-flowing granular materials indicate nv typically ranges between 0.65 and 0.80. This efficiency is not constant but varies with rotational speed, fill level, material properties, and wear state, necessitating empirical calibration and, in advanced systems, real-time compensation through closed-loop control [34].

III. Effect of Operating Parameters

Rotational Speed: While increasing the auger rotational speed (n) theoretically increases mass flow rate (ṁ = mactual × n), practical limits exist. Excessive speeds generate increased centrifugal forces that press particles against the casing wall, potentially altering friction dynamics and promoting particle attrition. Furthermore, high-speed operation exacerbates backflow and reduces the time available for material settling into the screw flights, potentially reducing volumetric efficiency [35].

Fill Level: The degree of screw channel filling significantly influences conveying dynamics. Optimal performance is typically achieved at fill levels between 40% and 80% of theoretical capacity. Underfilling leads to erratic, pulsating discharge, while overfilling increases compaction and power consumption without proportional throughput gains [20].

Particle-Scale Dynamics: DEM simulations by El Kassem (2021) demonstrate that material transport involves continuous particle rearrangement, with velocity gradients across the screw channel cross-section. Particles near the shaft exhibit lower axial velocities than those at the periphery, and transient force chains form and collapse during rotation, generating fluctuating torque requirements that must be accommodated by the servo drive system [36].

IV. | Integration with Mechatronic Control
| These complex rheological and kinematic behaviors establish that ideal mathematical models must be augmented with empirical efficiency factors and active mechatronic compensation to achieve high-precision industrial dosing. The inherent variability in bulk density, the non-linear relationship between screw rotation and material displacement, and the susceptibility to environmental moisture necessitate control architectures that transcend open-loop volumetric operation.
| Modern mechatronic systems address these challenges through the integration of adaptive microcontrollers implementing real-time volumetric correction factors. By periodically calibrating bulk density via auxiliary sensing or closed-loop feedback from load cells, the control system dynamically adjusts the required number of motor revolutions (Nreq ), effectively synthesizing the speed advantages of volumetric filling with the accuracy characteristics of gravimetric measurement. This hybrid approach, detailed in subsequent chapters, represents the contemporary engineering solution to the historical speed-accuracy trade-off in powder dosing systems [37].

### 2.3 Auger Filler Engineering State-of-the-Art

| The transition from theoretical granular mechanics to applied machine design necessitates a state-of-the-art approach to component engineering, wherein geometric optimization and material selection are governed by rigorous tribological, mechanical, and hygienic constraints. Modern volumetric dosing systems achieve industrial-grade precision not merely through control algorithms but through the meticulous engineering of the auger's macroscopic geometry and the strategic selection of advanced materials. This section delineates the contemporary engineering standards governing auger design for food-grade applications, with specific emphasis on the processing of crystalline Sodium Chloride (NaCl).
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

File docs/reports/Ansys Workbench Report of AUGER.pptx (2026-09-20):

## Ansys Workbench Report

Project

## Figure0001.png

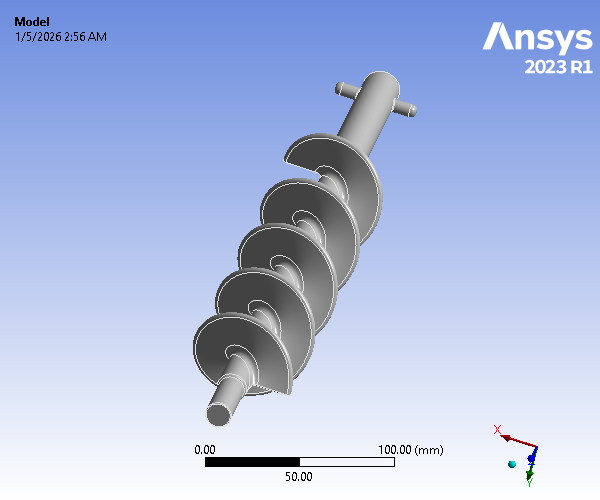
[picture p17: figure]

## Figure0002.png

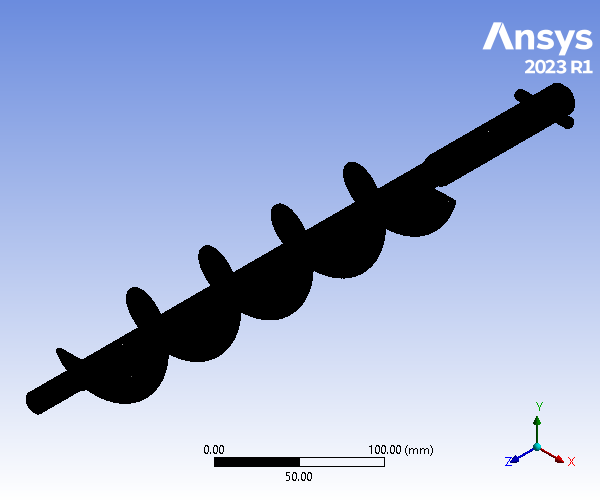
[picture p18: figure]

## Figure0003.png

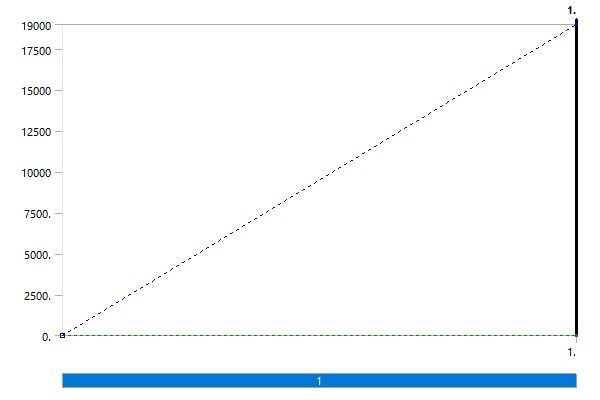
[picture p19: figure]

## Figure0004.png

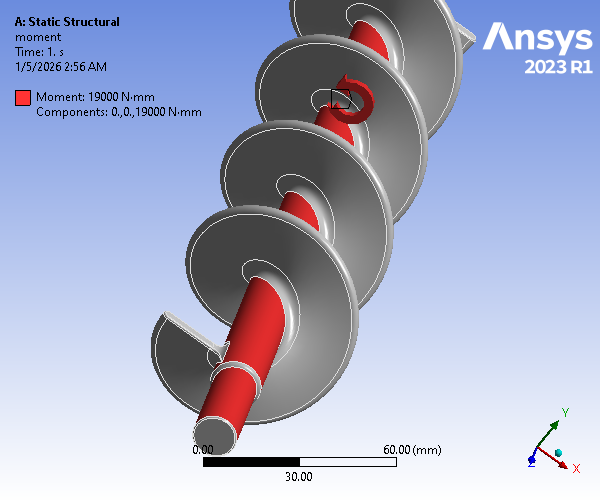
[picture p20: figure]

## Figure0005.png

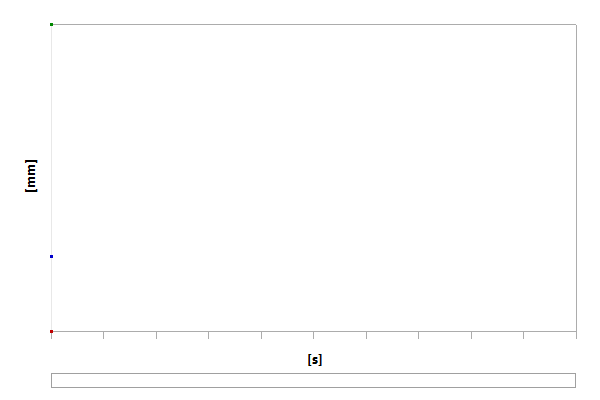
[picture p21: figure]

## Figure0006.png

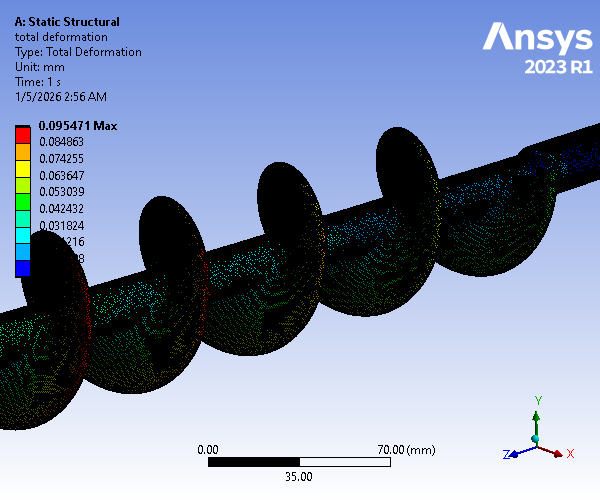
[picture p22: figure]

## Figure0007.png

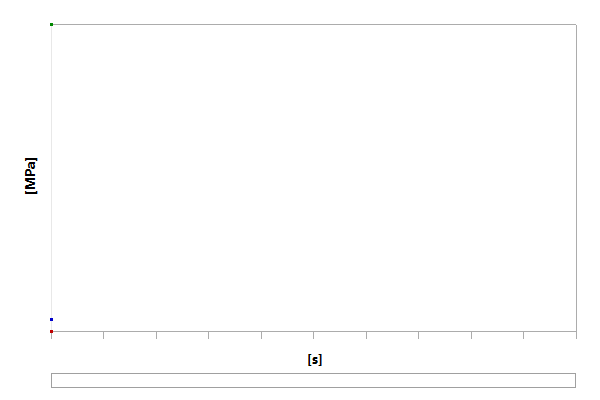
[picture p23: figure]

## Figure0008.png

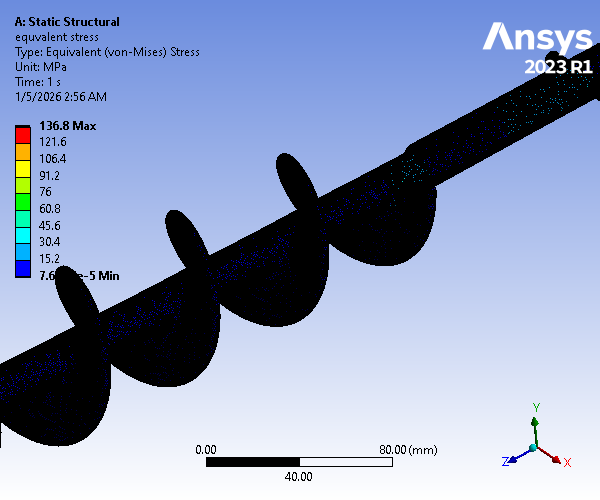
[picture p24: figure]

## Figure0009.png

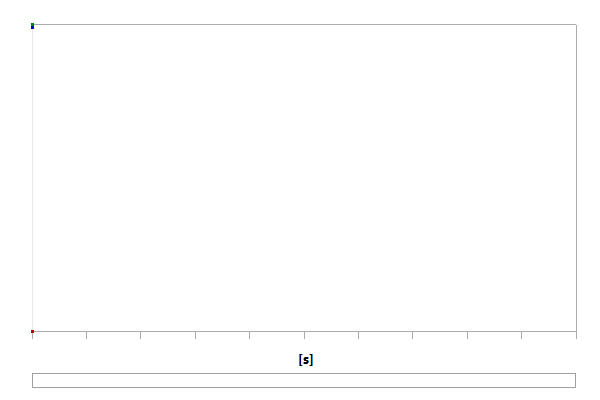
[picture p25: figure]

## Figure0010.png

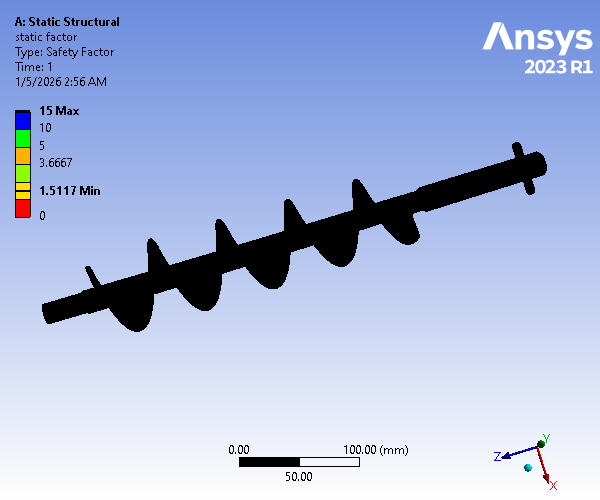
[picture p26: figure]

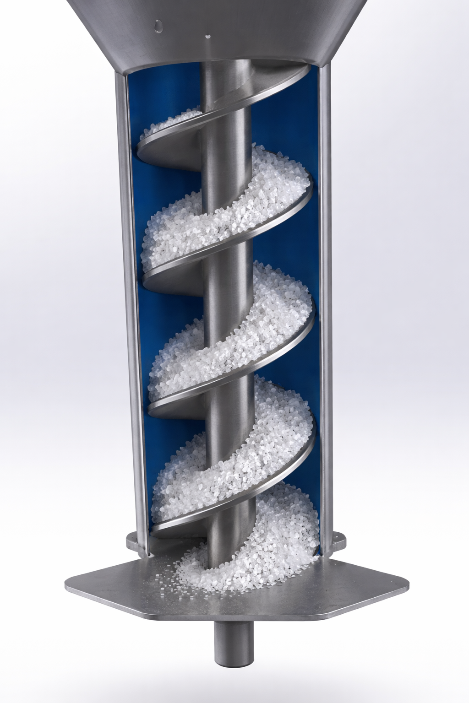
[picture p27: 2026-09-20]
docs/images/cad_renders/ChatGPT Image 26 reference_doc 2026reference_doc 02_58_44 reference_doc.png

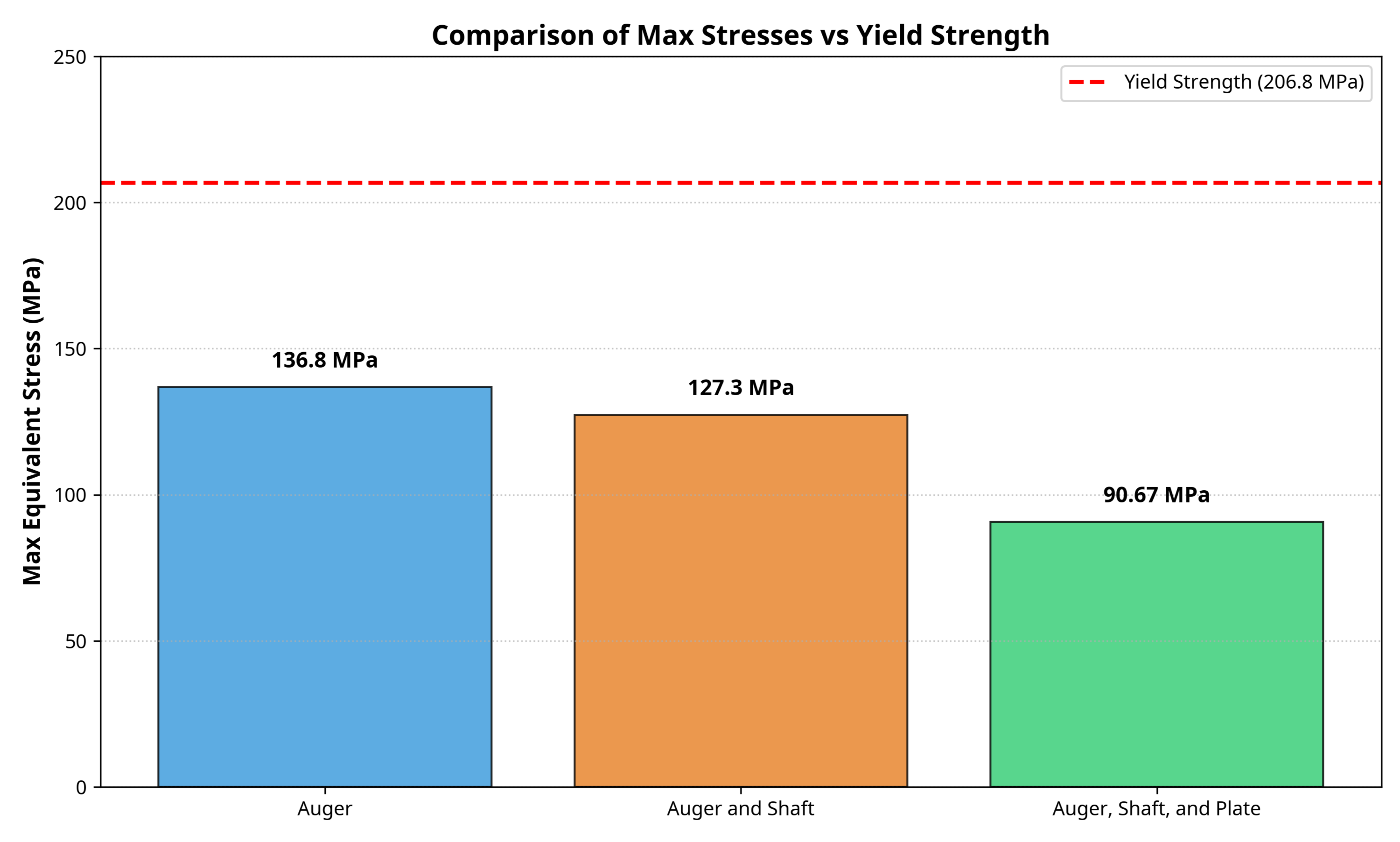
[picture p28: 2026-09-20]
docs/images/fea_plots/stress_comparison_chart.png

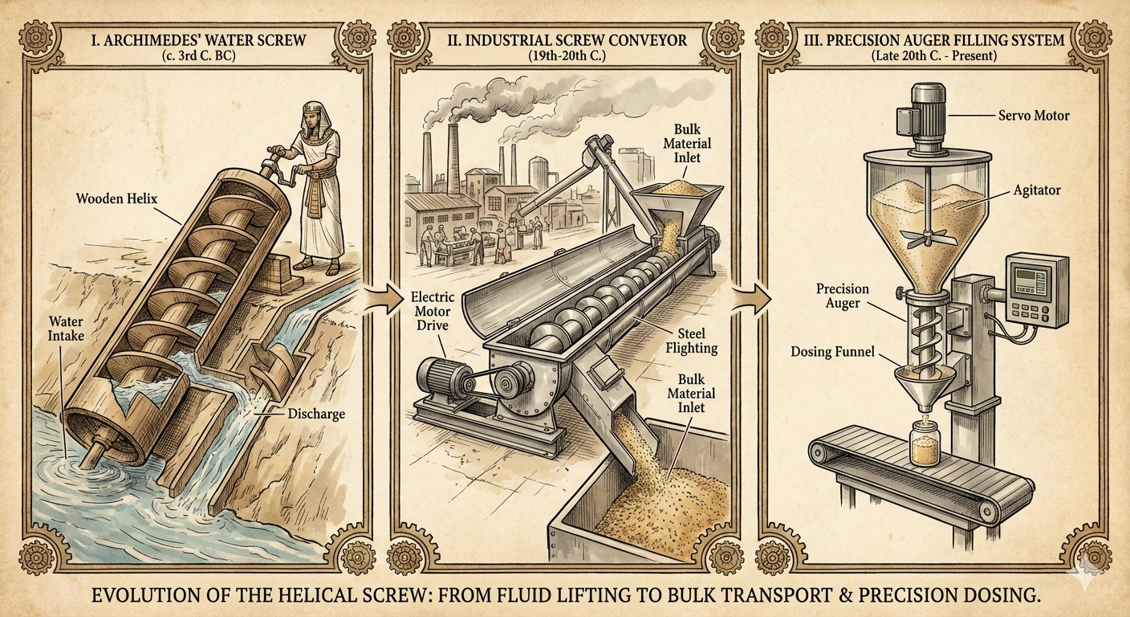
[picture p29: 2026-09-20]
docs/images/cad_renders/Gemini_Generated_Image_8mm1nl8mm1nl8mm1.png

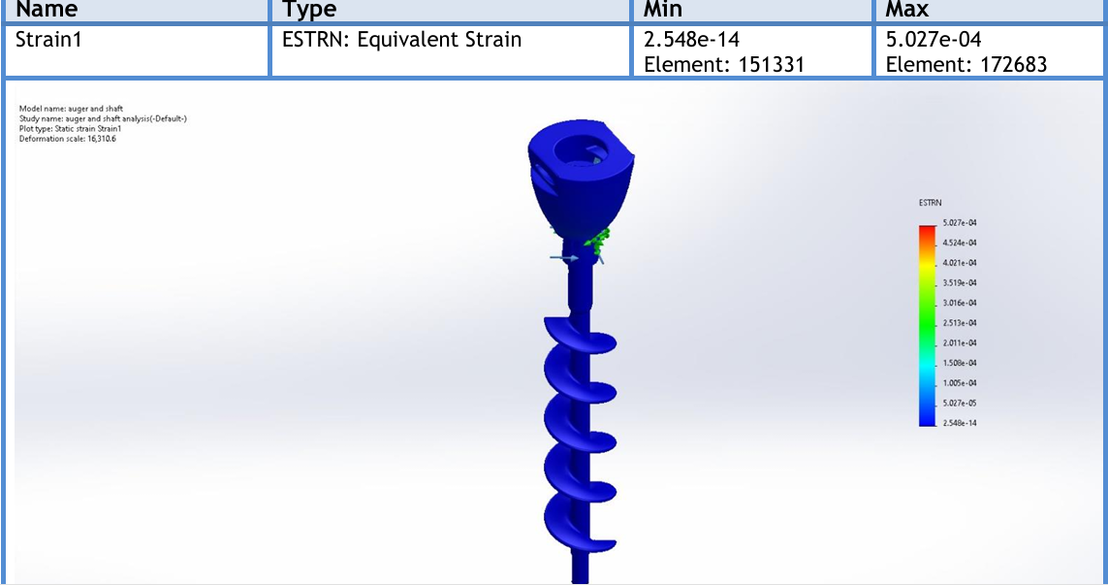
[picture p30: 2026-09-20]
docs/images/fea_plots/Auger and shaft Deformation.png

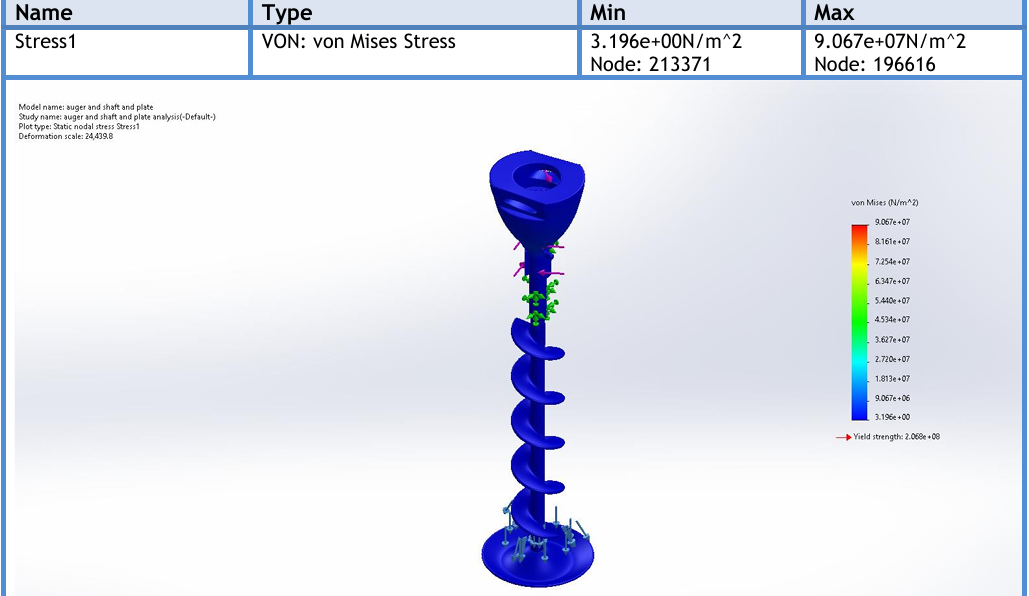
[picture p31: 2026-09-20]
docs/images/fea_plots/Auger and shaft and Panel Equivalent Stress.png

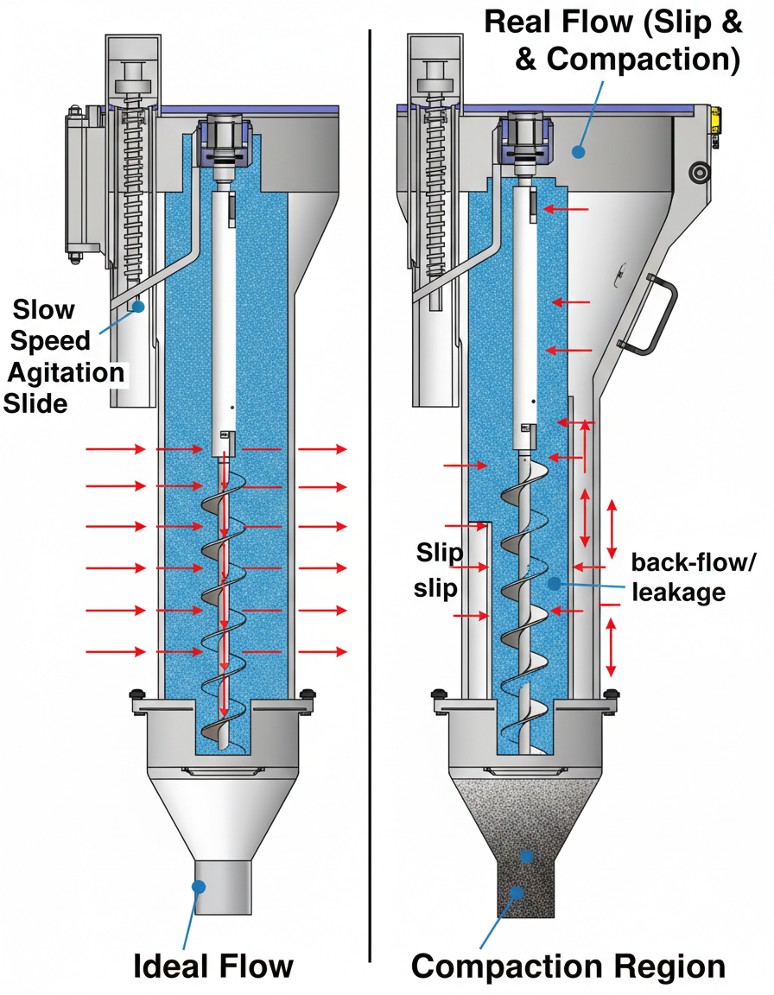
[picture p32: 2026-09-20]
docs/images/cad_renders/Gemini_Generated_Image_7reziz7reziz7rez.png

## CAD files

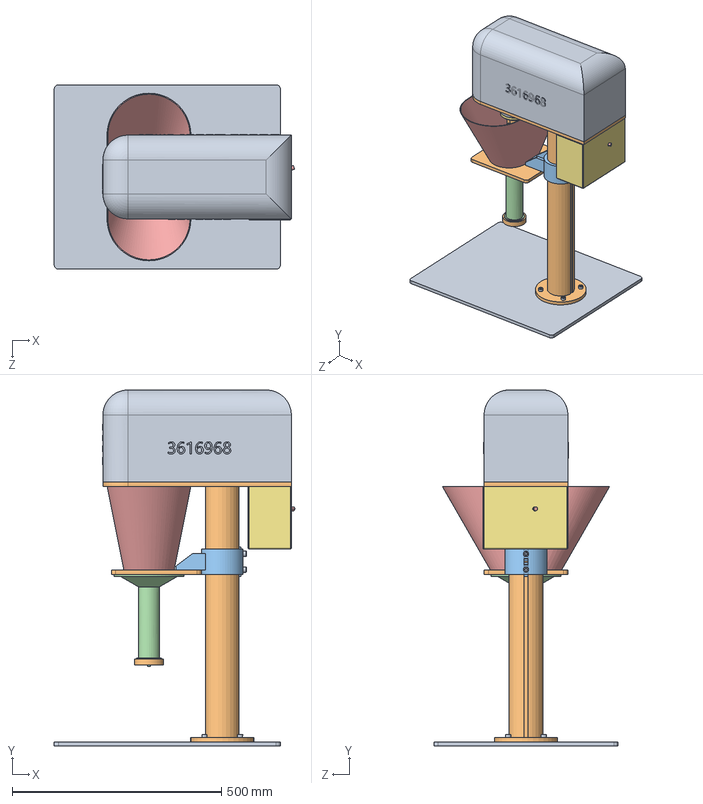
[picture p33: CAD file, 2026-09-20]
cad/assemblies/auger filler.SLDASM
574.4 x 850.0 x 440.0 mm
base
mainplate
shaft
funnel
hopper
top board
sleeve7
poprods x 4
outbearingseat
funelplate
funnelplateseat
_MSCI425EC_5__0__g_2
_8025Combination_Type__Parallel_Shaft_Gearheadmotor_4
_HTPA20S5M150_A_H15_b_2
blend motor case
augerscrew
hexagon socket head cap screws gb x 19
stand tube
washer x 2
topscrewplate
_AR66MC_5_PS_Gearhead_2
_AR66MC_5_PS_Motor_4
_HTPA50S5M150_A_H40_b_2
B6804ZZ
B6902ZZ
blenderseat
B6809ZZ x 2
MUEN45
MUEN15
B6702ZZ
blocker
blocker2
upcase4
end-cap
blenderauger

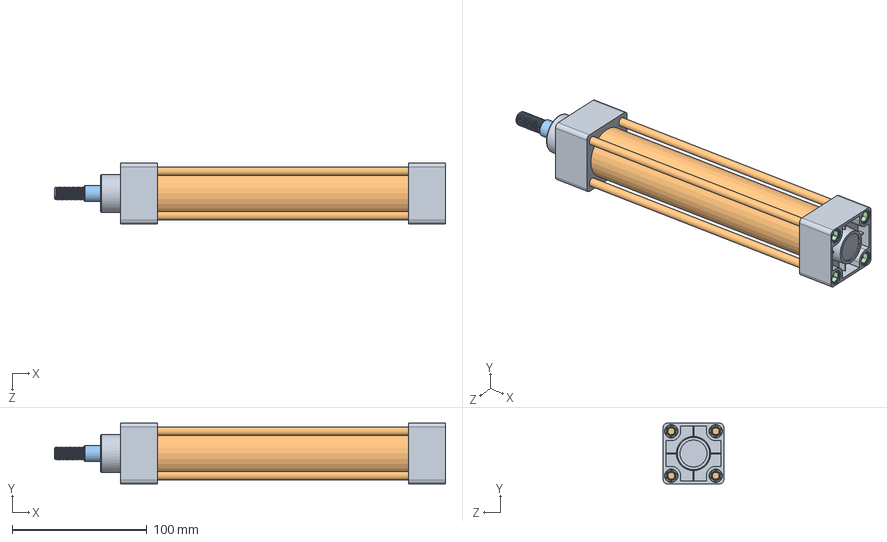
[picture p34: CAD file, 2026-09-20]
cad/assemblies/SC32.SLDASM
290.0 x 45.0 x 45.0 mm
SC32 Front and Back block x 2
Cylinder tube
SC32 Piston Rod
Tension nut x 8

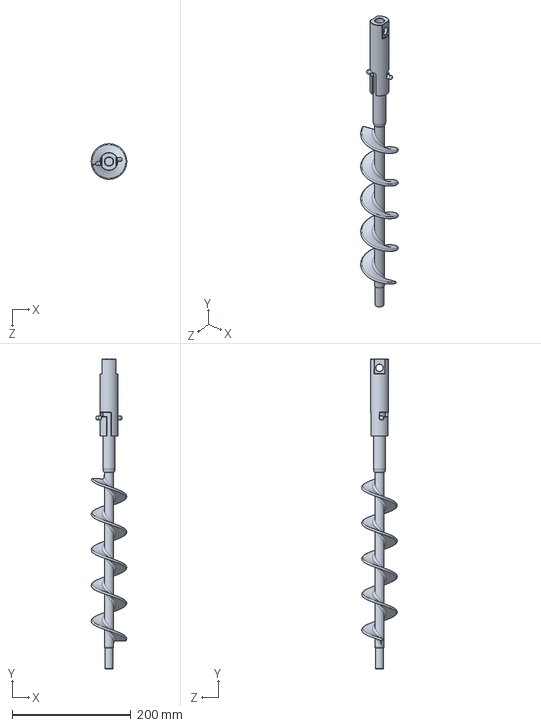
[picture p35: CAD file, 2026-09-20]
cad/parts/auger and shaft assembly.SLDPRT
60.0 x 522.3 x 60.0 mm

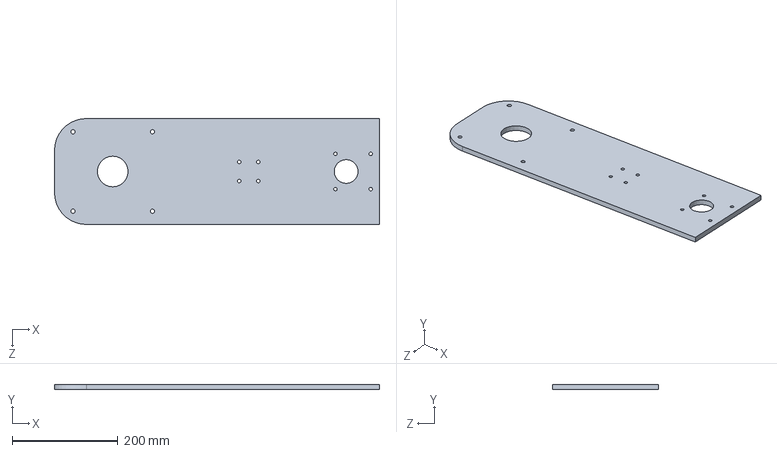
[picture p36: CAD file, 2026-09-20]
cad/parts/mainplate.SLDPRT
614.0 x 10.0 x 200.0 mm

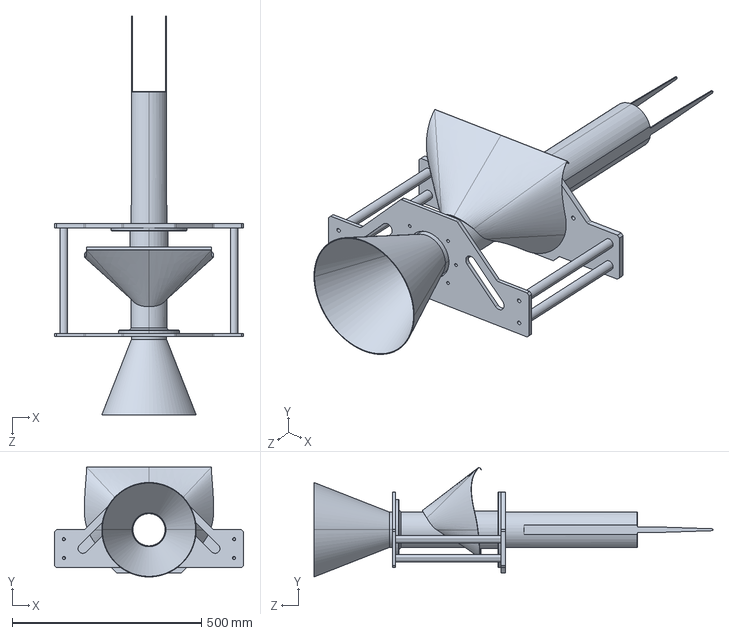
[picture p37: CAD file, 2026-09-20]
cad/parts/collar-assembly_asm.SLDPRT
500.0 x 290.7 x 1055.0 mm

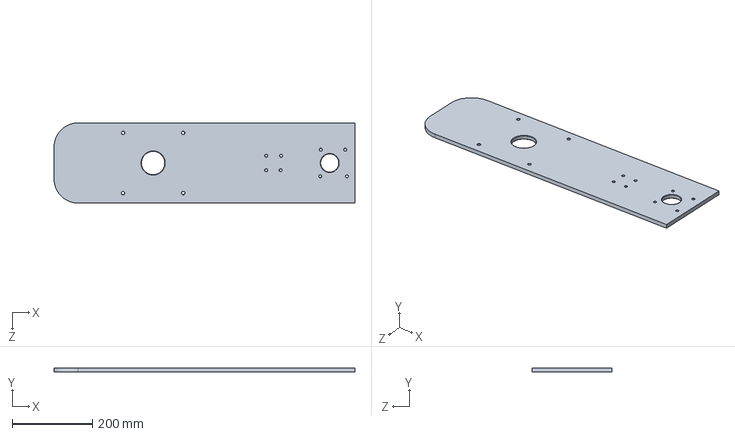
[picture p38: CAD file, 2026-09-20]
cad/parts/platemain.SLDPRT
750.0 x 10.0 x 200.0 mm

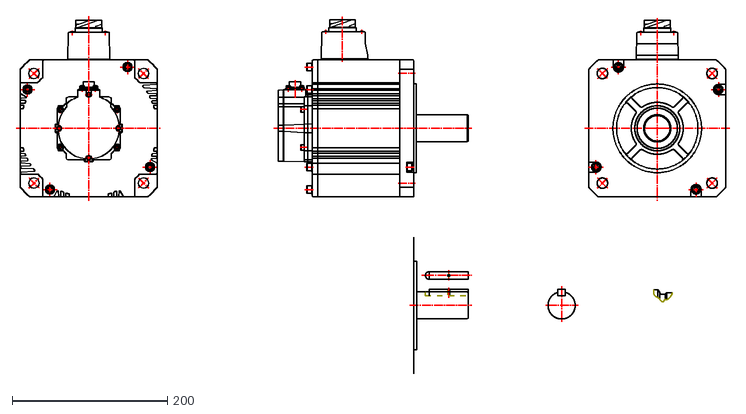
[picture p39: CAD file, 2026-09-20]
cad/drawings/MGMF442L1[]7_without_brake.dxf
919.6 x 460.7

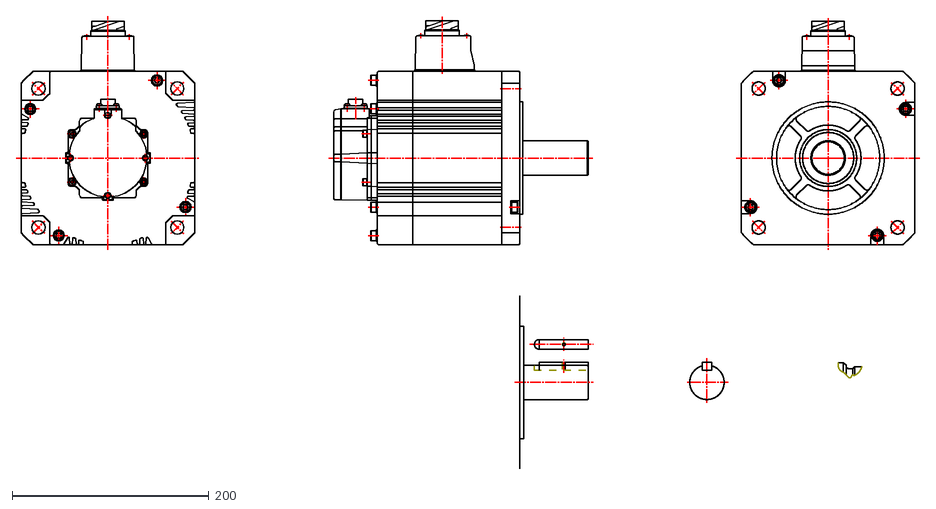
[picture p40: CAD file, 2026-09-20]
cad/drawings/MGMF292L1[]5_with_brake.dxf
919.6 x 460.7

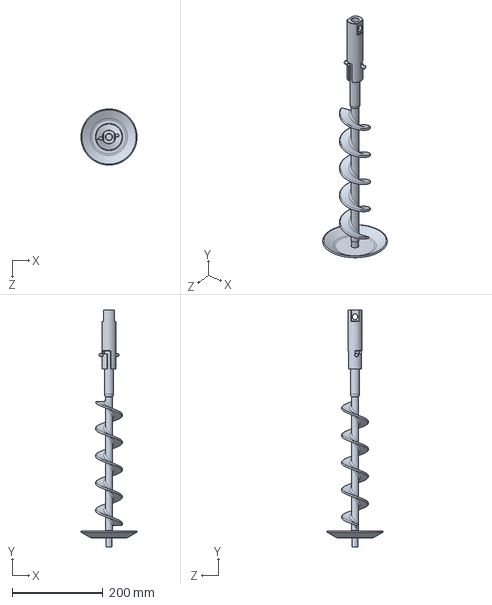
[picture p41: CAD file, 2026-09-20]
cad/parts/auger shaft plate ansys.SLDPRT
123.7 x 522.3 x 123.7 mm

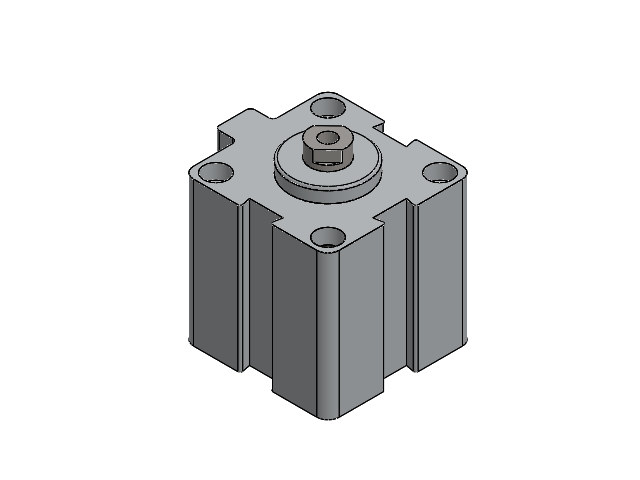
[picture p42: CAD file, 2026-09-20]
cad/assemblies/FESTO ADV - 50 - 25.SLDASM
cylinder ADV-50-25
pistion rod ADV-50-25-A

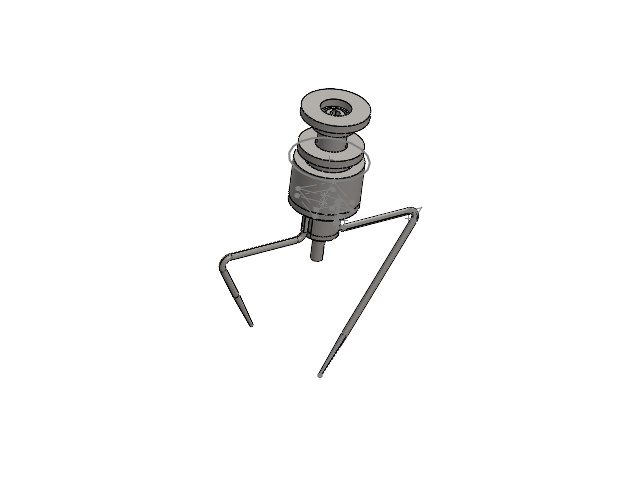
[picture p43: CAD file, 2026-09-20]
cad/assemblies/Assem4.SLDASM
shaft
B6804ZZ
B6902ZZ
B6702ZZ
MUEN15
blocker
blocker2
sleeve7
blenderseat
MUEN45
outbearingseat
blenderaugershortonly
blenderaugerlong
B6809ZZ x 2

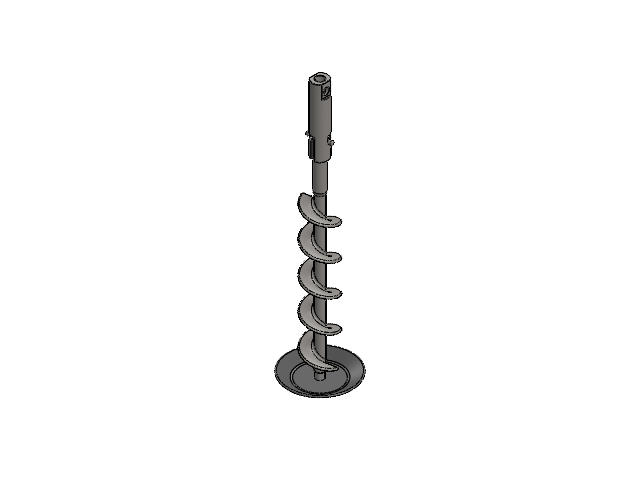
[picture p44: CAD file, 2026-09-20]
cad/assemblies/auger and shaft and plate.SLDASM
auger and shaft assembly
Spinner Plate

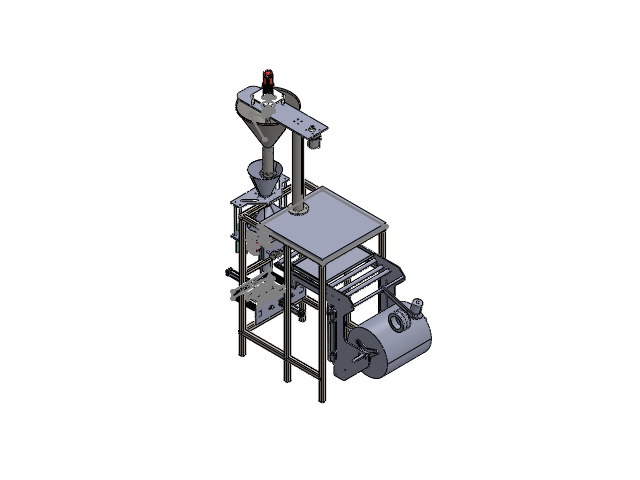
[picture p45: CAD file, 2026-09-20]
cad/assemblies/the complete shape vffs sys.SLDASM
collar-assembly_asm
stepper gear x 4
shaft grabbing mech x 2
Part1aaa
GRABBING PULLEY x 2
cross sealing plate n
frame
jaw guide x 2
SHF10 x 4
plate behined shock absorber x 2
Part1 heating bar new
Part1 heating bar2 new
plate behined jaw x 2
Allen Bolt x 4
damper spring new x 4
LMF10UU x 4
SC32 Front and Back block x 4
Cylinder tube x 2
SC32 Piston Rod x 2
Tension nut x 16
cutting tool fixing x 2
cutting tool
M6 Hex Socket Cap Screw 30mm.step x 2
hex nut jam_am x 2
Assem157
frame lognitudinal x 2
CYBASE x 2
cylinder ADV-50-25 x 2
pistion rod ADV-50-25-A x 2
LONG JAW2
LONGITUDINAL BACK SUPPORT x 2
LONG JAW
ROD x 4
cupper base x 4
machine wallL
funnel
stand tube - Copy
top board - Copy
topscrewplate - Copy
platemain
C-HTPA20S5M150-A-P15
shaft
B6804ZZ
B6902ZZ
B6702ZZ
MUEN15
blocker
blocker2
sleeve7
blenderseat
MUEN45
B6809ZZ x 2
outbearingseat
poprods x 4
hexagon socket head cap screws gb_GB_FASTENER_SCREWS_HSHCS M8X12-N_1 x 8
HTPA50S5M150-A-H40
gearbox_ab060a-020-s2-p1-14
MSME041G1U_msmf_gh_1.stp
MSME041G1U_key_1.stp
blenderaugerlong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

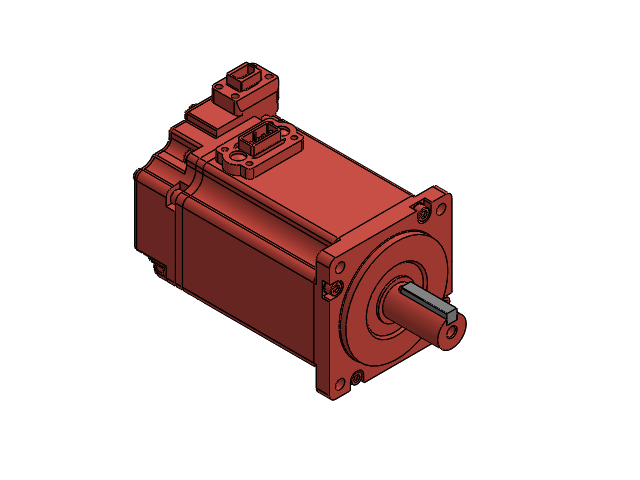
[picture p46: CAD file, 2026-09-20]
cad/assemblies/MSMF042L1U1.SLDASM
MSME041G1U_msmf_gh_1.stp
MSME041G1U_key_1.stp

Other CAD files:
cad/assemblies/new cross sealing assembly.SLDASM
cad/assemblies/Assembly.SLDASM
cad/assemblies/Assem123.SLDASM
cad/drawings/MGMF442L1[]5_with_brake.dxf
cad/parts/0.Auger (reference_doc reference_doc 444reference_doc).SLDPRT
cad/parts/Auger shaft.SLDPRT
cad/parts/Auger shafts.SLDPRT
cad/parts/Auger.SLDPRT
cad/parts/Cylinder tube.SLDPRT
cad/parts/LONG JAW.SLDPRT
cad/parts/LONG JAW2.SLDPRT
cad/parts/Part1 PLATE.SLDPRT
cad/parts/SHAFT ABOUD.SLDPRT
cad/parts/SHAFT ABOUDee.SLDPRT
cad/parts/auger and shaft and plate.SLDPRT
cad/parts/auger and shaft.SLDPRT
cad/parts/auger with out thread.SLDPRT
cad/parts/auger+shaft.SLDPRT
cad/parts/blenderauger.SLDPRT
cad/parts/blenderaugerlong.SLDPRT
cad/parts/blenderaugershort.SLDPRT
cad/parts/blenderaugershortonly.SLDPRT
cad/parts/blenderaugertall.SLDPRT
cad/parts/blenderseat.SLDPRT
cad/parts/blenderseat_7.SLDPRT
cad/parts/blenderseat_8.SLDPRT
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

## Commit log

2026-09-20 feat: initial clean release of VFFS packaging machine capstone project
    [0. Spinner Plate (reference_doc reference_doc reference_doc).SLDPRT, 0.Auger (reference_doc reference_doc 444reference_doc).SLDPRT, 0.Auger (reference_doc refe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]
2026-09-20 refactor: archive 2500+ non-essential files to _archive/, reduce tracked repo to 144 MB for GitHub push
    [0. Spinner Plate (reference_doc reference_doc reference_doc).SLDPRT, 0.Auger (reference_doc reference_doc 444reference_doc).SLDPRT, 0.Auger (reference_doc refe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]
2026-09-21 docs(flagship): deploy comprehensive VFFS whitepaper with visual CAD banners, KaTeX fixes, and system gallery
2026-09-21 fix(docs): replace hero banner with complete VFFS system assembly render
2026-09-21 fix(docs): replace fragile stateDiagram-v2 with bulletproof styled FSM flowchart

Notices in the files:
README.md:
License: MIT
